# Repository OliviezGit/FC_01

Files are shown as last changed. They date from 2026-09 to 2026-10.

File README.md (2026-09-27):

# FC_01

Projet KiCad H743_Ardupilot.

Le [dossier composants](composants/README.md) contient les fiches techniques PDF, bibliothèques locales, STEP, vues de contrôle et la nomenclature France du 27/09/2026.

- [Contrôle PDF complet](composants/controle/CONTROLE_COMPLET.pdf)
- [BOM France et références à commander](composants/BOM_FR.csv)
- [Rapport de vérification et réserves](verification/REPORT.md)

La présence des fichiers est vérifiée. La fabrication reste non libérée et quatre références fabricant restent sans offre France confirmée.

## État PCB

- PCB : **6 couches cuivre** configurées.
- Huaqiu 90 Ω : **0,2037 mm / 0,2451 mm** enregistré dans le projet.
- Routage : **0 piste, 0 via, 0 zone**.
- Revue CEM/implantation : voir [verification/REPORT.md](verification/REPORT.md).

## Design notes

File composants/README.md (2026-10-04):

# Dossier composants FC_01

## Ajout de bibliothèque du 04/10/2026

Le symbole exact `H743_Ardupilot:LMR604305SRAKRQ1`, son empreinte dédiée `H743_Custom:TI_RAK0009A_WQFN-HR-9_2.5x2.0mm_LMR604305` et le STEP RAK0009A fourni sont disponibles dans les bibliothèques actives. [Comparaison du ZIP, corrections et contrôles](kicad/LMR604305SRAKRQ1_IMPORT.md). Cet ajout ne remplace aucun composant placé et ne modifie pas la nomenclature du circuit existant.

Contrôle du 27 septembre 2026. **Le dossier est complet pour la présence des fichiers, mais la fabrication et l'approvisionnement ne sont pas entièrement validés.**

- [Rapport PDF complet](controle/CONTROLE_COMPLET.pdf) : 114 pages, empreintes, vues 3D, variantes de symboles et éléments PCB.
- [Nomenclature France](BOM_FR.csv) : 44 références fabricant, 133 composants achetés, prix EUR HT, minimum tarifaire, stock relevé, référence à commander et liens.
- [Inventaire machine](catalogue.json) : associations exactes repères / symbole / empreinte / STEP / PDF / fournisseur.
- [PDF techniques](pdf/) : 35 documents fabricant, dont certains couvrent plusieurs références. [Sources et SHA-256](pdf/SOURCES.json).
- [Bibliothèques KiCad actives](kicad/) : utilisées par les tables du projet. Les anciens fichiers `extralib/` restent des instantanés historiques.
- [Modèles 3D](3d/) : fichiers STEP locaux et [associations/transformations](3d/BINDINGS.json).
- [Éléments PCB](ELEMENTS_PCB.csv) : 22 repères constitués de cuivre ou de trous; symbole et empreinte présents, aucun achat ni composant 3D séparé applicable.

## Résultat

Les 155 repères possèdent un symbole et une empreinte locaux. Les 133 composants achetés possèdent un fichier STEP associé dans la bibliothèque et dans le PCB. Le contrôle indépendant vérifie 560 correspondances broche/pastille, sans écart dans le périmètre analysé. La fusion avec main au commit 8d4ebe12 préserve les positions, orientations et faces courantes. C13, supprimé du schéma dans main, a été retiré du PCB et des nomenclatures. Les pads C35.1, R19.1 et R18.2 suivent désormais la correction ADC_VBAT2 du schéma.

## Propriétés dans les schémas KiCad

Les champs sont renseignés sur **chaque instance de composant** dans les fichiers `.kicad_sch`, et contrôlés contre le catalogue. Les anciens champs DigiKey avec espaces sont synchronisés; les anciens tarifs et références d'autres offres non vérifiées sont effacés pour éviter les contradictions.

| Champ de la propriété du symbole | Contenu |
|---|---|
| `Footprint` / `Footprint_File` | Identifiant KiCad et fichier d'empreinte local. |
| `Symbol_ID` / `Symbol_Library_File` | Variante de symbole utilisée et bibliothèque locale. |
| `Model_3D` / `Model_3D_Type` | Fichier STEP local et nature du modèle, y compris les enveloppes simplifiées. L'association 3D active se trouve dans l'empreinte et dans le PCB. |
| `Datasheet` / `Datasheet_URL` | PDF technique local et URL de sa source. |
| `Component_PDF` | PDF de contrôle avec symbole, empreinte et vue du modèle 3D. |
| `Supplier` / `Supplier_Order_Code` / `Supplier_URL` | Fournisseur France retenu, référence exacte à commander et lien. |
| `Unit_Price_EUR` / `Price_Basis` / `Price_Qty` | Prix par pièce en EUR HT et quantité minimale correspondant au tarif. |
| `Stock_Units` / `Supplier_Status` | Stock relevé et statut, avec distinction entre rupture et offre non confirmée. |
| `Price_Checked` / `Stock_Checked` / `Supplier_Notes` | Date de consultation et réserves sur le relevé. |

Les champs non confirmés restent vides et sont accompagnés du statut explicite. Les 22 éléments fabriqués dans le PCB (pastilles, trous, cavaliers cuivre) portent une mention « non applicable » pour l'achat et le modèle 3D séparé, et un lien vers leur PDF de contrôle. Les 127 symboles d'alimentation/réseau sont aussi vérifiés contre la bibliothèque locale; ils n'ont pas de composant physique à commander. Au total : **282 instances de symboles examinées**, dont 155 repères PCB.

Exports de contrôle : [champs par composant](../verification/SCHEMA_FIELDS.csv) et [toutes les instances de symboles](../verification/SCHEMA_SYMBOLS.csv).

Neuf MPN utilisent une **enveloppe reconstruite**, clairement indiquée dans chaque fiche : LMR43620R5RPER, LMR604303SRAKRQ1, TJA1051TK/3,118, BMP581, DPS368XTSA1, Everlight 19-337/R6GHBHC-M01/2T, CSTNE8M00GH5C000R0, XGL4030-332MEC et DX07S016JA1R1500. Une enveloppe représente l'encombrement renseigné, pas les contacts ni une validation des tolérances. Les autres modèles sont génériques KiCad ou issus du STEP Amphenol fourni. Les modèles LSM6DSV16X et ICM-45686 ont une hauteur adaptée respectivement à 0.83 et 0.81 mm.

Les archives SnapMagic USBLC6 et JAE fournies ont servi de comparaison. Leur licence interdit la redistribution isolée : leurs STEP originaux et leurs versions transformées ne sont pas ajoutés ici. U1 utilise le SOT-666 KiCad; USB1 utilise une enveloppe indépendante. Les symboles et empreintes spécifiques au projet restent intégrés au circuit; ce dossier n'est pas une bibliothèque fournisseur destinée à une redistribution séparée.

## Achats à résoudre

| Repères | MPN exact | Résultat |
|---|---|---|
| R1, R2 | 0402WGF5101TCE | Offre exacte non retrouvée chez Farnell, RS et DigiKey France; prix, stock et code de commande non confirmés. |
| D1 | 19-337/R6GHBHC-M01/2T | Même réserve. |
| R9 | RC0402FR-0716K5L | Référence trouvée à l'international, offre France non confirmée. |
| L1, L2 | XGL4030-332MEC | Fiche DigiKey Marketplace à l'international; disponibilité et tarif France non confirmés. |

Aucune substitution n'a été appliquée. Les données absentes sont laissées vides, jamais remplacées par zéro. Un stock nul indique une rupture sur la page consultée; un stock vide signifie non confirmé. Les disponibilités sont des relevés web, pas des réservations. Les pages peuvent être indexées avec retard.

Pour C1005X5R1C225M050BC, Farnell France 2525017 affiche 0.104 EUR HT par pièce **à partir de 10**, minimum et multiple de 10. La page indexée est ancienne et annonce une vente jusqu'à épuisement : prix et stock à reconfirmer. Le TJA1051TK/3,118 annonce une dernière date d'achat au 26/12/2026 sur DigiKey : cycle de vie à revoir avant approvisionnement.

## Contrôles restant ouverts

Voir [verification/REPORT.md](../verification/REPORT.md). ERC/DRC natifs KiCad non exécutés; le contrôleur indépendant ne développe pas les quatre nets du bus MOTOR. Les pads alternatifs U1/U10/U11, le masque U13, la pâte U5/U6 et le plan complet USB1 requièrent encore validation. Les quatre composants ajoutés dans la revue précédente restent en zone provisoire et leur placement/routage n'est pas terminé.

```sh
python3 tools/verify_design.py
python3 tools/check_connectivity.py
```

Les PDF de contrôle sont des rendus indépendants des fichiers KiCad, pas une sortie native de KiCad. Les numéros et connexions complets se trouvent dans [PINS.csv](../verification/PINS.csv). Les fiches techniques restent la référence pour les spécifications électriques complètes.

## Provenance

Les PDF fabricant et modèles tiers conservent leurs droits d'origine. Les commentaires de licence et noms d’auteur des STEP KiCad sont conservés. Une adresse personnelle présente dans un en-tête a été retirée; la section géométrique STEP est inchangée, et cette modification est tracée dans 3d/SOURCES.json. Les enveloppes paramétriques sont générées par `tools/localize_component_assets.py`; `tools/build_component_catalog.py` et `tools/render_component_catalog.py` régénèrent le catalogue. Dépendances : Python, CadQuery, NumPy, Matplotlib, PyMuPDF, ReportLab et polices DejaVu.

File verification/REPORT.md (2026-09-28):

# FC_01 — revue composants et bibliothèques

**Mise à jour du 28/09/2026 :** voir [RULES_LEVIA_COMPARISON_2026-09-28.md](RULES_LEVIA_COMPARISON_2026-09-28.md) pour les règles courantes, [PLACEMENT_NATIVE_DRC_2026-09-28.md](PLACEMENT_NATIVE_DRC_2026-09-28.md) pour le placement et [FULL_DESIGN_REVIEW_2026-09-28.md](FULL_DESIGN_REVIEW_2026-09-28.md) pour la revue fonctionnelle précédente. Les autres rapports et sections ci-dessous décrivent des révisions antérieures; leurs coordonnées et résultats ne doivent pas être utilisés pour le PCB courant.

Date : 2026-09-27. Base initiale : `8023e116a3f5c59ac772a055e0b58ddf85dce90a`. Fusion avec main : `8d4ebe12d84cf1e334181edc0c4434b1bac12989`.

**État : corrections intégrées, revue statique terminée ; fabrication non libérée.**
Le projet contient 155 références physiques, 44 MPN distincts et 560 broches/pads numérotés. Les 155 références disposent désormais d'un symbole et d'une empreinte résolus dans le dépôt. Le contrôle statique ne remplace pas KiCad ERC/DRC, une vérification électrique du circuit, ni une qualification d'assemblage.

## Revue implantation / CEM — mise à jour du 27/09/2026

Le PCB courant est désormais configuré en **6 couches cuivre** : F.Cu, In1.Cu, In2.Cu, In3.Cu, In4.Cu et B.Cu. Le routage n'a pas commencé : **0 segment, 0 via et 0 zone cuivre**. Le preset différentiel Huaqiu 90 ohms est enregistré dans le projet à **0,2037 mm de largeur / 0,2451 mm d'espacement**.

Les remarques CEM/implantation ont été rapprochées du fichier PCB courant :
- **USB1/U1/R1/R2** : le chevauchement courtyard a été supprimé. La marge courtyard USB1→U1 est d'environ **0,22 mm** ; la validation mécanique finale reste ouverte tant que le plan primaire coté JAE n'est pas archivé.
- **J12 microSD** : l'empreinte Amphenol 10067099-200LF Rev.H est intégrée ; la validation mécanique finale reste requise.
- **VCAP C7/C10** : corrigés sur **F.Cu**, au même côté que le STM32H743. C7 est maintenant à **(87,50 ; 94,05), 90°** et C10 à **(102,50 ; 98,40), 0°**, afin de réduire les boucles VCAP.
- **Y1 8 MHz** : reste actuellement sur **B.Cu**. Il ne doit pas être déplacé sur F.Cu sans réorganisation du bloc 9 V, car **L2 occupe actuellement la zone immédiatement sous OSC_IN/OSC_OUT**. Ce point reste bloquant avant routage.
- **U4/L2 9 V** : la cellule doit encore être repackée ; le feedback R10/R11 et la position de L2 sont à optimiser en même temps que le déplacement de Y1, avec nœud SW minimal et feedback éloigné de SW.
- **D5 / U8 CAN** : D5 est déjà placée au bord du connecteur U8 ; les courtyards sont séparés d'environ **0,47 mm**. Le routage devra conserver connecteur → protection ESD → transceiver sans stub.
- **BMI088 / BMP581** : les keepouts de routage/vias/métal constructeur restent à matérialiser dans KiCad avant routage.
- **Plans internes** : les 6 couches sont créées, mais les plans GND/POWER ne sont pas encore matérialisés par des zones ; la CEM finale ne pourra être validée qu'après routage, stitching et DRC.

## Modifications

| Référence | Correction appliquée |
|---|---|
| U14 | Empreinte JST SH 9 contacts remplacée par la variante SM08B à 8 contacts correspondant au MPN ; pattes 9/10 reliées GND. |
| U5, U6 | Empreinte dédiée Diodes U-DFN3030-8 Type E ; EP 1.60 × 2.35 mm et pads périphériques conformes au plan. Fenêtres de pâte EP à qualifier avec l'assembleur. |
| D2 | Empreinte Diodes SMA avec pads 2.50 × 1.70 mm, centres espacés de 4.00 mm. Ancien modèle Littelfuse conservé dans ses fichiers historiques, mais plus affecté à D2. |
| U12 | Dimensions des six pads haut/bas BMP581 corrigées à 0.300 × 0.325 mm ; ouverture masque sous corps ajoutée selon Bosch. |
| D1 | Noms de broches corrigés : 1 BK, 2 RK, 3 GK, 4 BA, 5 RA, 6 GA ; numéros et fils conservés. Empreinte Everlight dédiée ajoutée. |
| U11 | Empreinte LGA14 ajoutée ; cinq marqueurs NC déplacés sur les extrémités des broches. **GND reste en 6 et VDD en 8**, comme indiqué par TDK. |
| U13, Y1 | Empreintes locales DPS368 et résonateur Murata ajoutées. |
| R34, R35, R36 | Affectations des nets aux pads 1/2 du PCB remises en accord avec le schéma. |
| D4, D5, U8 | Liens datasheet, noms de pins D5 et métadonnée de boîtier GH corrigés. |

Y1, D1, U11 et U13 sont désormais intégrés au PCB courant ; l'ancienne zone d'attente à x=230 mm n'est plus l'état de référence. Le placement actuel du PCB fait foi. Y1 reste néanmoins à reprendre côté F.Cu après réorganisation du bloc 9 V, comme indiqué dans la revue implantation/CEM ci-dessus. C13, supprimé du schéma dans main, est retiré du PCB et des nomenclatures (151 empreintes héritées conservées). La correction ADC_VBAT2 du schéma est reportée sur C35.1, R19.1 et R18.2; aucun segment routé ne portait cet ancien net. Les nets internes hérités de noms de pins D1 peuvent conserver leur ancien libellé ; les connexions numériques sont inchangées.

Les symboles utilisés sont figés dans `composants/kicad/FC01_Project.kicad_sym`, avec un nom distinct par feuille/variante pour préserver les personnalisations. Les empreintes standard utilisées sont copiées depuis le PCB dans `composants/kicad/vendor/` et référencées par `fp-lib-table`. Il s'agit d'instantanés de ce projet, pas d'une mise à jour vers la dernière bibliothèque KiCad. Les 133 composants achetés disposent de modèles STEP locaux. Neuf MPN utilisent une enveloppe reconstruite, sans contacts détaillés; voir `../composants/3d/BINDINGS.json`. Les fichiers `extralib/` historiques restent conservés, mais les tables pointent désormais sur `composants/kicad/`.

La nomenclature actuelle est `../composants/BOM_FR.csv`. Prix et stocks ont été recherchés sur les sites France le 27/09/2026. Quatre MPN restent sans offre France confirmée. Le tarif Farnell C1005X5R1C225M050BC est à partir de 10 pièces et sa source indexée est ancienne. `BOM_DigiKey.csv` est synchronisé avec ces données.

## Preuves et portée

- [COMPONENTS.csv](COMPONENTS.csv) : une ligne par référence, MPN, boîtier, symbole, empreinte, statut et source.
- [PINS.csv](PINS.csv) : une ligne par pin avec nom, net PCB, NC et dimensions/positions de pad. Pour les pads `custom`, `size` est la taille de l'ancre ; le polygone complet fait foi.
- [EVIDENCE.json](EVIDENCE.json) : constat par MPN, détails dimensionnels et réserves.
- [SOURCE_HASHES.json](SOURCE_HASHES.json) : empreintes SHA-256 des PDF effectivement téléchargés et examinés. Les 35 PDF techniques sont désormais archivés dans `../composants/pdf/`; le manifeste courant est `../composants/pdf/SOURCES.json`.
- [CHECKS.json](CHECKS.json) : résultats du contrôle reproductible.
- [SCHEMA_FIELDS.csv](SCHEMA_FIELDS.csv) : propriétés effectivement enregistrées sur les 155 instances de composants des schémas, avec liens locaux, données d'achat et réserves.
- [SCHEMA_SYMBOLS.csv](SCHEMA_SYMBOLS.csv) : les 282 instances de symboles, y compris les 127 symboles d'alimentation/réseau sans composant physique.

Les statuts `MANUFACTURER_LAND_*` concernent les dimensions citées, pas une certification de fabricabilité. `PACKAGE_REVIEWED_STANDARD_LAND` et `FAMILY_PACKAGE_REVIEWED` indiquent un boîtier/famille reconnu avec empreinte standard conservée ; ils ne prétendent pas reproduire un land pattern constructeur spécifique. Les listes de pins exportées constituent une preuve de cohérence des fichiers, pas à elles seules une validation indépendante de toutes les fonctions électriques.

## Contrôles exécutés

Depuis la racine du dépôt :

```sh
python3 tools/verify_design.py
python3 tools/check_connectivity.py
```

Le validateur vérifie : ensembles de références, résolution des bibliothèques locales, égalité symbole embarqué/bibliothèque, ensembles de numéros de pins/pads, géométrie des pads PCB/bibliothèque après normalisation de face/orientation, rattachement UUID et cohérence des groupes de nets. Il ne modifie aucun fichier sans `--write`.

Il contrôle également les propriétés de chaque composant du schéma contre le catalogue, l'existence de ses fichiers locaux et la cohérence des anciens champs commerciaux avec le fournisseur France retenu. Les prix non confirmés sont vides. Les anciens champs USB1 (tarif de bobine et URL erronée), C7/C10 (ancienne offre DigiKey) et les autres valeurs périmées ont été corrigés; les 3D simplifiées restent explicitement identifiées.

Résultat : **155/155 références, 560 pins/pads, zéro erreur dans le périmètre analysé**. La géométrie des nouveaux pads a également été examinée sur un rendu technique indépendant. Les quatre nets `/MCU/MOTOR1` à `/MCU/MOTOR4` traversent un bus vectoriel que le script ne développe pas : ils sont explicitement exclus du rapprochement entre groupes et restent à vérifier nativement. Les alias de bus et les croisements complexes requièrent aussi le contrôle natif.

## Points ouverts avant fabrication

1. **KiCad 10** : ouvrir le projet, mettre à jour le PCB depuis le schéma (F8), comparer les changements proposés, exécuter ERC puis DRC après placement/routage. `kicad-cli` n'est pas disponible ici ; aucun résultat ERC/DRC natif n'est annoncé.
2. **USB1/JAE** : obtenir le plan coté complet et valider les ancrages/courtyard avant fabrication. Le STEP fourni a été orienté et ses contacts rapprochés des pads. **J12/Amphenol** : plan Rev.H maintenant archivé et relu, STEP orienté, corps et contacts cohérents avec le plan; validation d’assemblage reste requise.
3. **L1/L2 Coilcraft** : le plan mécanique document 1575-4 du 19/12/2022 est maintenant archivé et confirme les pads 0.98 × 3.40 mm, entraxe 2.37 mm. L’offre commerciale France reste non confirmée. Le modèle local est une enveloppe nominale.
4. **U1/U10/U11** : confirmer avec l'assembleur les pads alternatifs conservés/créés. Pour U1, l'empreinte fournisseur SOT-666 est conservée ; elle diffère du dessin conseillé par ST. Pour U11, les dimensions du boîtier et le brochage sont confirmés, mais les extensions de pads sont un choix IPC de projet.
5. **U13 et U5/U6** : approuver respectivement le recouvrement masque SMD choisi (cuivre 0.45, ouverture 0.35 mm) et les quatre fenêtres de pâte thermique. Contrôler les contraintes de montage/nettoyage des capteurs de pression.
6. Réaliser le placement, les dégagements mécaniques, le routage, les contrôles d'alimentation/intégrité des signaux et les sorties de fabrication. Cette revue ne certifie pas le fonctionnement du contrôleur de vol.

Les anciens rapports d'audit du dépôt décrivent des états antérieurs. Pour les modifications de cette révision, ce dossier et les fichiers de conception courants font foi.

## Complément documentaire et approvisionnement

Voir [composants/README.md](../composants/README.md) et le [contrôle PDF complet](../composants/controle/CONTROLE_COMPLET.pdf). Les tests vérifient désormais aussi présence locale et égalité des associations 3D PCB/bibliothèque. Les modèles d’enveloppe ne sont pas des modèles détaillés certifiés fabricant.

## Corrections CEM / pré-routage — 27/09/2026 soir

- Netclasses KiCad créées : `POWER`, `USB_90R`, `CAN`, `SENSITIVE`; affectations initiales enregistrées dans le projet. La géométrie USB reste à recalculer/valider contre le stack-up fabricant réel avant routage.
- Cellule 9 V : R10/R11 rapprochées de U4/FB, L2 éloignée de la zone oscillateur; C19 rapprochée de U4. Le routage SW/PGND/FB reste à réaliser selon la boucle minimale du constructeur.
- Buck 5 V : C17 rapprochée de U3 VIN/GND.
- U7 : TJA1051TK/3,118 EOL remplacé au schéma par TJA1057GTK/3Z, brochage /3 et boîtier HVSON8/SOT782 compatibles à conserver lors de la synchronisation PCB.
- D2 : SMAJ30CA non validée pour protection des buck 42 V (clamp max trop élevé). SMAJ24CA identifiée comme piste de correction, mais non imposée car VRWM=24 V est inférieur au 25,2 V d'un pack 6S plein; choix final de protection transitoire encore ouvert.
- Y1 : déplacement final et zone oscillateur dédiée encore ouverts; aucune implantation arbitraire n'a été imposée.
- BMI088/BMP581 : keepouts constructeur cuivre/vias encore à matérialiser précisément dans le PCB.
- SDIO_CLK : résistance série optionnelle encore à intégrer proprement au schéma + PCB; ne pas modifier seulement le PCB.

## Pré-routage CEM — application 27/09/2026

- Y1: zone oscillateur matérialisée; résonateur rapproché du MCU, keepout cuivre/vias local B.Cu et keepout opposé F.Cu pour interdire un convertisseur directement en vis-à-vis.
- BMI088 U9: keepout footprint corrigé pour être local au composant et couvrir la zone sous boîtier; pistes/vias/copper pour interdits dans la zone définie.
- BMP581 U12: keepout sous boîtier ajouté, avec pistes/vias/copper pour interdits; pads autorisés.
- SDIO_CLK: R47 22 ohms ajoutée en série côté source dans MICRO_SD, 0402; option 0 ohm après validation SI. Empreinte synchronisée sur PCB et net carte séparé.
- D2 / architecture VBAT: décision gelée — conserver SMAJ30CA, U3 LMR43620 et U4 LMR60430-Q1. Pas d'eFuse/clamp actif et pas de passage à des buck 60–100 V. Le système est conçu pour VBAT 6S (25,2 V max normal); la SMAJ30CA est une protection transitoire, pas une garantie de clamp <42 V dans toutes les conditions.
- Plans GND In1/In4 ajoutés, ainsi qu'une première couronne de vias de stitching GND périphériques.
- Routage signal complet NON réalisé: le PCB était encore à 0 segment avant cette passe et un routage automatique non revu serait contraire à l'objectif CEM. Les boucles buck, USB 90 ohms, CAN et retours capteurs doivent être routés/revus explicitement.
- ERC/DRC KiCad 10 NON exécuté dans cet environnement: kicad-cli n'est pas disponible. Ne pas considérer la carte libérable avant ouverture/sauvegarde KiCad 10 puis ERC/DRC natifs.

## Décision architecture VBAT / D2 / buck — 27/09/2026

Décision finale pour cette révision: conserver l'architecture simple existante.

- Entrée: VBAT 6S, 25,2 V maximum en fonctionnement normal.
- D2: SMAJ30CA conservée.
- U3: LMR43620 conservé.
- U4: LMR60430-Q1 conservé.
- Aucun eFuse/clamp actif ajouté.
- Aucun remplacement des buck par des versions 60/80/100 V.
- D2 doit rester implantée au plus près de l'entrée VBAT/GND avec boucle de décharge courte et large.
- Les condensateurs d'entrée de chaque buck doivent rester directement associés aux broches VIN/PGND; minimiser les boucles chaudes VIN-SW-PGND.
- Limite documentée: la valeur Vc maximale de la SMAJ30CA à son courant d'essai peut dépasser 42 V; D2 réduit les surtensions mais n'est pas spécifiée comme écrêteur garanti sous l'absolute maximum des buck pour toute impulsion possible.
- Cette limitation est acceptée pour la révision 6S actuelle; elle devra être réévaluée si l'entrée batterie, le câblage, l'ESC, la capacité bulk ou la tension maximale changent.

## Revue placement / corrections — 27/09/2026

- Collision de référence corrigée: la résistance série SDIO_CLK est désormais R51 (22 ohms, option 0 ohm après validation SI). R47 reste exclusivement la résistance MOTOR1 200 ohms.
- PCB synchronisé manuellement pour R51; net SDIO_CLK -> R51 -> J12 CLK conservé.
- L2 déplacée légèrement à (91.6,117.6) pour augmenter l'écart à Y1 sans allonger excessivement la boucle SW U4-L2. Le routage SW_9V devra rester compact et orienté à l'opposé de Y1.
- Découplages H743 rapprochés de la périphérie MCU: C6, C8, C11, C12. Les couloirs d'évasion du LQFP100 sont conservés; aucune piste n'est encore routée.
- Découplages capteurs resserrés: C44/C47 autour de U11, C46/C49/C52 autour de U9, C53 autour de BMP581. U10 était déjà correctement découplé localement.
- Connectique contrôlée: CAN J13/J14/U8 reste sur la périphérie; I2C J8/J9 en bord inférieur; ESC U14 en bord gauche; USB1 en bord supérieur. Cette organisation est conservée pour éviter des traversées inutiles de la zone MEMS.
- Séparation puissance/capteurs: L1/U3 restent côté gauche; U9/U10/U11/U12/U13 côté droit. Les nets SW_5V et SW_9V ne devront pas être routés sous la zone MEMS ni sous Y1.
- Statut: placement nettement plus proche du gel, mais validation DRC et inspection visuelle KiCad 10 requises avant freeze définitif.

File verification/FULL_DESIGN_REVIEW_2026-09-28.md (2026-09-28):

# FC_01 — revue schéma, PCB, empreintes et placement (28/09/2026)

État du PCB : **pré-routage, non libéré pour fabrication**. Les deux faces F.Cu/B.Cu et les trous traversants ont été examinés. Les 22 références figées (connecteurs, fixations, U8, U14, USB1) restent à leur emplacement initial.

## Corrections de cette passe

| Cellule | Changement | Résultat géométrique |
|---|---|---|
| U6, C30, C32 | U6 orienté 270°; condensateurs entrée/sortie remis du côté de leurs broches respectives | U6.8→C30.1 : **5,02 → 2,14 mm**; U6.1→C32.1 : **1,61 → 1,93 mm**. Trous USB1 libres. |
| U5, C29, C31 | U5 et ses deux condensateurs retournés sur place, pads alimentation vers le LDO | U5.8→C29.1 : **3,51 → 1,96 mm**; U5.1→C31.1 : **3,66 → 2,23 mm**. |
| U3, L1 | L1 retournée sans déplacer son corps | Broche SW U3.5→L1.1 : **3,87 → environ 3,43 mm**. |
| U9 BMI088 | Ouverture de pâte des 16 pads périphériques diminuée de 0,025 mm par côté sur le PCB et l'empreinte locale | Ouverture 0,20 × 0,625 mm pour pad 0,25 × 0,675 mm : **74,1 % de l'aire cuivre**. |

Les distances sont entre centres de pads, en projection 2D : elles aident à comparer les implantations mais ne mesurent ni longueur routée ni aire de boucle. Aucun composant figé n'a bougé.

## Rapprochement statique

| Contrôle | Résultat |
|---|---|
| Schéma ↔ PCB | **156/156 références**, **562/562 couples broche/pad**; empreintes PCB ↔ bibliothèques locales cohérentes; zéro erreur dans `verify_design.py`. |
| Réseaux | 456 broches avec noms de nets comparées indépendamment; zéro discordance. Aucune fusion ou séparation inattendue des groupes. Les quatre couples MCU↔résistance MOTOR1–4 sont comparés explicitement; développement complet des bus à contrôler dans KiCad. |
| Courtyards F.Cu/B.Cu | Aucun recouvrement entre composants d'une même face détecté par `audit_placement.py`. |
| Face opposée / traversants | Aucun contact trou traversant ↔ pad SMD ou courtyard opposé détecté par `audit_through_holes.py`; la projection seule des composants sur deux faces n'est pas une collision physique. |
| Oscillateur et références figées | Y1 du même côté F.Cu que U2; keepout opposé libre; 22 références figées sans déplacement. |
| Routage | **0 piste, 0 via, 2 zones**. Les deux zones ne remplacent pas un remplissage et un DRC natif. |

## Comparaison aux fiches constructeur archivées

| Bloc | Prescription vérifiée | Constat / point restant |
|---|---|---|
| U5/U6 AP7361C | Au moins 1 µF à l'entrée, 2,2 µF à la sortie, céramiques proches de IN/OUT et GND ([fiche](../composants/pdf/AP7361C.pdf)). | C29–C32 : 4,7 µF nominaux; les pads d'alimentation sont à 1,93–2,23 mm des broches utiles. Capacité effective sous polarisation et retour GND à confirmer. |
| U3 LMR43620 | CIN, VCC, BOOT proches; nœud SW court; FB à l'écart du SW ([fiche](../composants/pdf/U3_datasheet.pdf), §9.5.1). | U3→C16 1,88 mm; →C20 1,60 mm; →C21 2,74 mm; SW→L1 ~3,43 mm. Boucles et masse à mesurer après routage. |
| U4 LMR60430-Q1 | Même discipline CIN/BOOT/SW/FB et cuivre thermique ([fiche](../composants/pdf/U4_datasheet.pdf), §8.4.1). | U4→C19 1,61 mm; →C22 2,55 mm; FB→R10 1,22 mm; SW→L2 4,03 mm. Chemin SW, dissipation, épaisseur de cuivre et masse restent à valider. |
| U2 STM32H743, Y1 | Découplage et VCAP près des broches; résonateur HSE proche des entrées ([fiche](../composants/pdf/U2_datasheet.pdf)). | U2→C7 1,88 mm, →C10 1,94 mm; Y1 sur F.Cu, à 4,13/3,19 mm des broches HSE. VCAP 2,2 µF nominal; ESR et capacité effective à confirmer. |
| U9 BMI088 | Stencil signal 70–90 % de la surface pad, épaisseur 80–150 µm ([fiche](../composants/pdf/U9_datasheet.pdf), §8.5). | 74,1 % après correction; épaisseur de stencil à spécifier à l'assembleur. U9 est sous la projection du MCU sur l'autre face : vérifier mécanique/thermique. |
| U12 BMP581 | Pad allongé de 25 µm, séparation ≥200 µm, ni piste ni via sous le capteur; contraintes de masque ([fiche](../composants/pdf/U12_datasheet.pdf), §8.2). | Keepout local B.Cu et pads 0,300 × 0,325 mm présents. Les couches internes et la fenêtre de masque sous le corps restent à confirmer dans KiCad et auprès de l'assembleur. |
| USB1 | Validation du connecteur JAE et des ancrages. | Trous et pads dégagés sur les deux faces. Le PDF JAE archivé n'est pas un plan coté complet : validation mécanique fabricant encore ouverte. |

## Avant libération

Ouvrir le projet dans KiCad, mettre à jour le PCB depuis le schéma en examinant le diff, exécuter ERC puis DRC natifs, remplir les zones et router. Contrôler alors impédance USB selon l'empilage réel, retours de courant, boucles SW, chemins de protection ESD et dégagements 3D. Examiner les points ouverts U12, USB1, VCAP et stencil avec les fiches et l'assembleur. **Aucun ERC/DRC natif n'a été exécuté dans cet environnement**, où `kicad-cli`/`pcbnew` ne sont pas installés; ce rapport ne certifie pas le fonctionnement électrique ou la fabricabilité.

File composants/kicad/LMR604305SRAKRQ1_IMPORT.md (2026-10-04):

# LMR604305SRAKRQ1 — bibliothèque FC_01

Mise à jour du 04/10/2026 à partir de l'archive `LMR604305SRAKRQ1.zip` fournie par l'utilisateur et de la fiche TI LMR60430-Q1, SNAS875E, révision E.

## Utilisation dans KiCad

- Symbole : `H743_Ardupilot:LMR604305SRAKRQ1`.
- Empreinte : `H743_Custom:TI_RAK0009A_WQFN-HR-9_2.5x2.0mm_LMR604305`.
- STEP : `${KIPRJMOD}/composants/3d/LMR604305SRAKRQ1_RAK0009A.step`.
- Les tables de bibliothèques du projet enregistrent déjà `H743_Ardupilot` et `H743_Custom`; aucune configuration supplémentaire n'est nécessaire.

Le composant est disponible pour insertion. Cette mise à jour des bibliothèques ne remplace aucun composant dans les schémas ou dans le PCB.

## Comparaison et corrections

Le symbole du ZIP comporte le brochage exact de la référence 5 V. Ses types électriques SW `power_in` et FB/MODE/RT `unspecified` ne sont pas repris tels quels. Le symbole ajouté utilise la présentation compacte existante du projet, les types ci-dessous et la référence fabricant exacte. Aucun code fournisseur de la référence 3,3 V n'est recopié.

| Broche | Fonction | Type KiCad |
|---|---|---|
| 1 | VIN | power_in |
| 2 | PGND | power_in |
| 3 | SW | power_out |
| 4 | BOOT | passive |
| 5 | PG | open_collector |
| 6 | FB | input |
| 7 | MODE/SYNC | input |
| 8 | RT | passive |
| 9 | EN | input |

BOOT est passif pour représenter le raccordement bootstrap par condensateur sans demander une source d'alimentation externe sur ce nœud. RT est passif pour représenter sa résistance de programmation; PG est une sortie à drain ouvert représentée par le type KiCad `open_collector`.

L'empreinte brute du ZIP dessine plusieurs plages de cuivre comme graphiques `F.Cu`, séparées des pastilles circulaires, et numérote les trois trous thermiques 10, 11 et 12. Ces numéros ne sont pas des broches du composant RAK à neuf broches. L'empreinte intégrée reprend les pastilles personnalisées électriquement connectées de FC_01, ses ouvertures de masque et de pâte, son repère de broche 1 et sa cour intérieure, avec le STEP fourni. Elle ne contient ni cuivre graphique flottant ni pastille 10–12. Les vias thermiques éventuels doivent être posés sur le réseau PGND pendant le routage; les recommandations TI de remplissage, bouchage ou tenting doivent être prises en compte selon le procédé de fabrication.

La géométrie cuivre/masque/pâte est conservée à l'identique de l'empreinte locale existante. Une variante dédiée à la référence 5 V évite de changer les associations historiques et les empreintes déjà placées.

## Contrôles exécutés

- Lecture structurée des fichiers KiCad et absence de noms de symboles dupliqués.
- Les sept symboles précédents de la bibliothèque sont conservés à l'identique; un huitième symbole est ajouté.
- Brochage 1–9 comparé au symbole fourni et à la table TI, page 4.
- Contrôle des neuf pastilles électriques, du lien symbole/empreinte et des chemins de bibliothèques actifs.
- Comparaison de la géométrie au fichier local précédent et revue du plan TI RAK0009A, pages 43–45.
- STEP fourni lu par OpenCascade : dix solides, neuf contacts alignés sur les neuf pastilles; encombrement 2,0 × 2,5 × 0,8 mm et origine de montage Z = 0.
- Le STEP est copié sans modification. SHA-256 : `45047d72ab90321aa5fd37295c414bddf8963955413e9c0bb3c3ade36f1926e9`.

KiCad natif n'est pas installé dans cet environnement : ces contrôles ne constituent pas un ERC/DRC natif ni une validation de fabrication. La validation électrique du convertisseur, son implantation, ses vias thermiques et son intégration au schéma restent distinctes de cette mise à jour de bibliothèque.

Source TI : https://www.ti.com/lit/gpn/LMR60430-Q1

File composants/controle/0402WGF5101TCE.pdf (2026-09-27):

FC_01 / DOSSIER COMPOSANTS / 27.09.2026

# 0402WGF5101TCE

R1 / R2

UNI-ROYAL(Uniroyal Elec) - 5.1K -

Quantité carte : 2 | Broches et pastilles : contrôle structurel concordant.
Achat : Farnell / RS / DigiKey France | référence commande non confirmée
Prix : NON CONFIRMÉ | Stock relevé : non confirmé

Reference exacte: offre France, prix et stock non confirmes. Ne pas commander via une substitution implicite.

PDF technique local : composants/pdf/Royalohm.pdf
Lien de téléchargement de la fiche technique (https://www.royalohm.com/assets/pdf/products/smd/1.pdf)
EMPREINTE / mm | MODÈLE 3D LOCAL

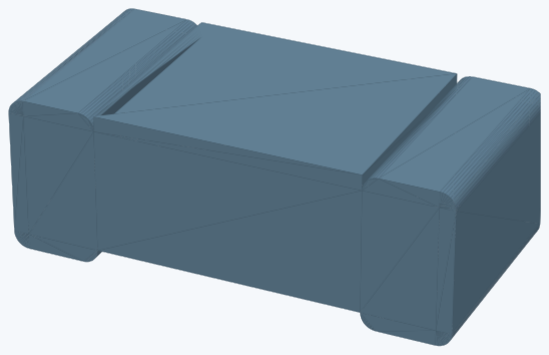
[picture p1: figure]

1 2

Cuivre ocre / corps bleu / cour dessin gris - vue dessus

3D : KiCad, geometrie generique du boitier

Empreinte : Resistor_SMD:R_0402_1005Metric
STEP : composants/3d/R_0402_1005Metric.step

Contrôle documentaire : Royalohm Thick Film Chip Resistors pp.1,3: 0402 1.00±0.10 x 0.50±0.05 mm; code 5101=5.1 kohm, F=1%. Deux bornes non polarisées; pads KiCad conservés.

Lecture indépendante des fichiers KiCad. Aucun ERC/DRC natif exécuté. | 1

FC_01 / DOSSIER COMPOSANTS / 27.09.2026

# 0402WGF5101TCE

SYMBOLE / FC01_Project:H743_Ardupilot__R_Small

Repères : R1, R2

SYMBOLE / CORPS ET NUMÉROS DES BROCHES

1

2

Correspondance complète : verification/PINS.csv

Rendu vectoriel de la variante utilisée; champs de nomenclature en page précédente. | 2

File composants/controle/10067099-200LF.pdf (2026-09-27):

FC_01 / DOSSIER COMPOSANTS / 27.09.2026
10067099-200LF

J12

Amphenol ICC (FCI) - 10067099-200LF - microSD, SMD right-angle top-mount, 10 positions (8+2), H=2.65 mm

Quantité carte : 1 | Broches et pastilles : contrôle structurel concordant.
Achat : DigiKey France | 609-5773-1-ND
Prix : 0.7800 EUR HT / pièce, tarif quantité 1 | Stock relevé : 32954

Ouvrir la fiche fournisseur France (https://www.digikey.fr/fr/products/detail/amphenol-icc-fci/10067099-200LF/4238739)

Relevé web; stock et prix variables.

PDF technique local : composants/pdf/10067099.pdf Lien de téléchargement de la fiche technique (https://www.mouser.com/datasheet/2/18/1/10067099-2577377.pdf)

EMPREINTE / mm | MODÈLE 3D LOCAL

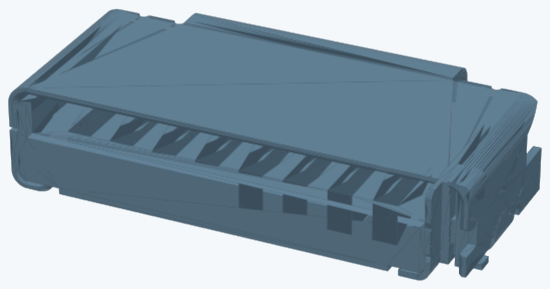
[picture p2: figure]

8 | 7 | 6 | 5 | 4 | 3 | 2 | 1

10

9

Cuivre ocre / corps bleu / cour dessin gris - vue dessus

3D : STEP fournisseur fourni par utilisateur; orientation rapprochee du plan Rev.H

Empreinte : H743_Custom:Amphenol_10067099-200LF_RevH
STEP : composants/3d/Amphenol_10067099-200LF_aligned.step

Contrôle documentaire : Plan Amphenol 10067099 Rev.H p.2: version 200LF hauteur 2.65 mm, 8 contacts pas 1.10 mm + 2 detecteurs. Plan local et STEP fournisseur rapproches de l empreinte; validation assemblage reste a faire.

Lecture indépendante des fichiers KiCad. Aucun ERC/DRC natif exécuté. | 1

FC_01 / DOSSIER COMPOSANTS / 27.09.2026
10067099-200LF

SYMBOLE / FC01_Project:MICRO_SD__Micro_SD_Card

Repères : J12

SYMBOLE / CORPS ET NUMÉROS DES BROCHES

1
DAT2

2
DAT3/CD

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
DAT0

8
DAT1

9

CD1

# 10CD²

Correspondance complète : verification/PINS.csv

Rendu vectoriel de la variante utilisée; champs de nomenclature en page précédente. | 2

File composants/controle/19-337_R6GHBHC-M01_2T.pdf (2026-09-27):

FC_01 / DOSSIER COMPOSANTS / 27.09.2026

# 19-337/R6GHBHC-M01/2T

D1

Everlight Electronics - 19-337/R6GHBHC-M01/2T - 6-SMD, 1.6x1.6x0.35 mm

Quantité carte : 1 | Broches et pastilles : contrôle structurel concordant.
Achat : Farnell / RS / DigiKey France | référence commande non confirmée
Prix : NON CONFIRMÉ | Stock relevé : non confirmé

Reference exacte: offre France, prix et stock non confirmes. Ne pas commander via une substitution implicite.

PDF technique local : composants/pdf/D1_datasheet.pdf
Lien de téléchargement de la fiche technique (https://uploadcdn.oneyac.com/attachments/files/brand_pdf/everlight/BB/85/19337R6GHBHCM012T.pdf)
EMPREINTE / mm | MODÈLE 3D LOCAL

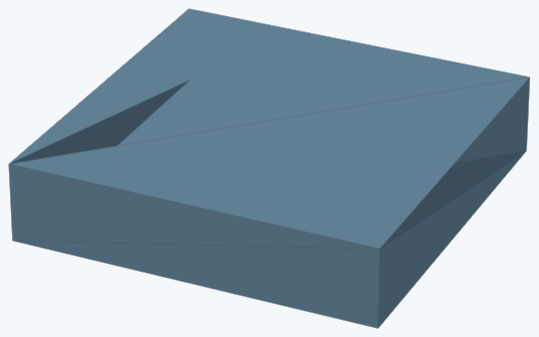
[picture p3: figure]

1

2

3

4

5

6

Cuivre ocre / corps bleu / cour dessin gris - vue dessus

3D : ENVELOPPE RECONSTRUITE: volume du boitier uniquement; contacts et tolerances non representes

Empreinte : H743_Custom:Everlight_19-337_1.6x1.6mm
STEP : composants/3d/Everlight_19-337_envelope.step

Contrôle documentaire : Everlight DSE0007440 Rev2 p.2: 1BK 2RK 3GK 4BA 5RA 6GA. Noms corrigés sans changer numéros/fils. Corps 1.6 x 1.6; centres x±0.7, y±0.75 et 0; pads extrêmes 0.6 x 0.5, centraux 0.6 x 0.6. Placement PCB à terminer.

Lecture indépendante des fichiers KiCad. Aucun ERC/DRC natif exécuté. | 1

FC_01 / DOSSIER COMPOSANTS / 27.09.2026

# 19-337/R6GHBHC-M01/2T

SYMBOLE / FC01_Project:MCU__LED_RGB_EP_1

Repères : D1

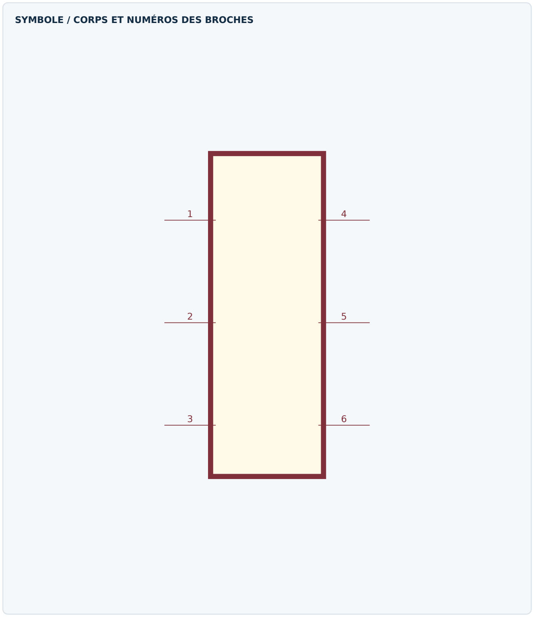
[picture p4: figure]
SYMBOLE / CORPS ET NUMÉROS DES BROCHES

Correspondance complète : verification/PINS.csv

Rendu vectoriel de la variante utilisée; champs de nomenclature en page précédente. | 2

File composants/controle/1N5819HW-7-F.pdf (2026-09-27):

FC_01 / DOSSIER COMPOSANTS / 27.09.2026

# 1N5819HW-7-F

D4

Diodes Incorporated - 1N5819HW-7-F - SOD-123

Quantité carte : 1 | Broches et pastilles : contrôle structurel concordant.
Achat : DigiKey France | 1N5819HW-FDICT-ND
Prix : 0.2700 EUR HT / pièce, tarif quantité 1 | Stock relevé : 711720

Ouvrir la fiche fournisseur France (https://www.digikey.fr/fr/products/detail/diodes-incorporated/1N5819HW-7-F/814970)

Relevé web; stock et prix variables.

PDF technique local : composants/pdf/1N5819HW.pdf Lien de téléchargement de la fiche technique (https://media.digikey.com/pdf/Data%20Sheets/Diodes%20PDFs/1n5819hw%20%202.pdf)

EMPREINTE / mm | MODÈLE 3D LOCAL

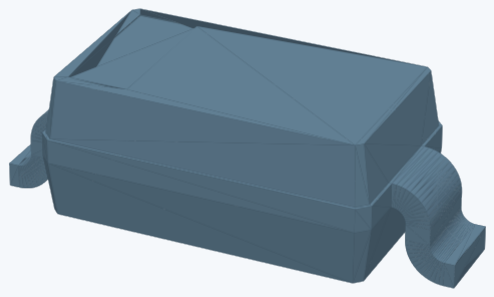
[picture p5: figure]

1 2

Cuivre ocre / corps bleu / cour dessin gris - vue dessus

3D : KiCad, geometrie generique du boitier

Empreinte : Diode_SMD:D_SOD-123
STEP : composants/3d/D_SOD-123.step

Contrôle documentaire : Diodes 1N5819HW-7-F: SOD-123, 1 cathode 2 anode. Lien datasheet corrigé (ancienne fiche Hottech 1N5819WS incorrecte).

Lecture indépendante des fichiers KiCad. Aucun ERC/DRC natif exécuté. | 1

FC_01 / DOSSIER COMPOSANTS / 27.09.2026

# 1N5819HW-7-F

SYMBOLE / FC01_Project:POWER__1N5819WS

Repères : D4

SYMBOLE / CORPS ET NUMÉROS DES BROCHES

1 | 2

Correspondance complète : verification/PINS.csv

Rendu vectoriel de la variante utilisée; champs de nomenclature en page précédente. | 2

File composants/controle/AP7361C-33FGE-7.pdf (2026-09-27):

FC_01 / DOSSIER COMPOSANTS / 27.09.2026

# AP7361C-33FGE-7

U5 / U6

Diodes Incorporated - AP7361C-33FGE-7 - U-DFN3030-8 Type E; exposed pad 1.6 x 2.35 mm

Quantité carte : 2 | Broches et pastilles : contrôle structurel concordant.
Achat : DigiKey France | AP7361C-33FGE-7DICT-ND
Prix : 0.4900 EUR HT / pièce, tarif quantité 1 | Stock relevé : 3118

Ouvrir la fiche fournisseur France (https://www.digikey.fr/en/products/detail/diodes-incorporated/AP7361C-33FGE-7/5638320)

Relevé web; stock et prix variables.

PDF technique local : composants/pdf/AP7361C.pdf Lien de téléchargement de la fiche technique (https://docs.sparkfun.com/SparkFun_GNSS_Flex_System/SparkFun_GNSS_Flex_Breakout/assets/component_documentation/AP7361C.pdf)

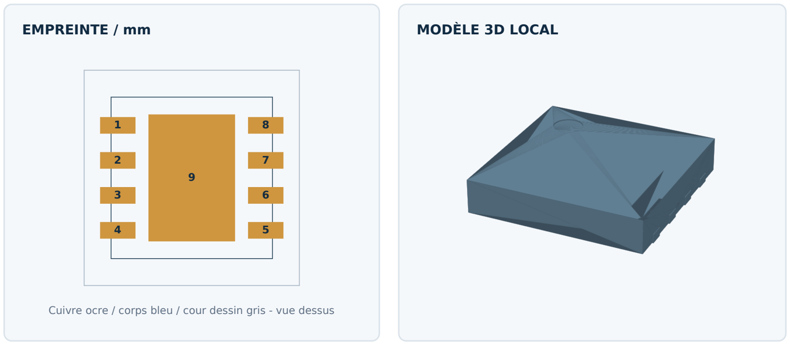
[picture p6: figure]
EMPREINTE / mm; MODÈLE 3D LOCAL

Cuivre ocre / corps bleu / cour dessin gris - vue dessus

3D : KiCad: EP nominal 1.5 x 2.25, pads PCB maximaux 1.6 x 2.35 (Diodes p.17/20)

Empreinte : H743_Custom:Diodes_U-DFN3030-8_TypeE
STEP : composants/3d/DFN-8-1EP_3x3mm_P0.65mm_EP1.5x2.25mm.step

Contrôle documentaire : AP7361C FGE = U-DFN3030-8 Type E. Pads périphériques 0.65 x 0.30, pas 0.65; EP9 1.60 x 2.35 mm. Stencil EP découpé en 4 fenêtres, couverture 64% (choix projet à qualifier). EP relié GND; pads NC conservés.

Lecture indépendante des fichiers KiCad. Aucun ERC/DRC natif exécuté. | 1

FC_01 / DOSSIER COMPOSANTS / 27.09.2026

# AP7361C-33FGE-7

SYMBOLE / FC01_Project:POWER__AP7361C-33FGE-7

Repères : U5, U6

SYMBOLE / CORPS ET NUMÉROS DES BROCHES

1
OUT

2
NC

3
ADJ/NC

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
Correspondance complète : verification/PINS.csv

Rendu vectoriel de la variante utilisée; champs de nomenclature en page précédente. | 2

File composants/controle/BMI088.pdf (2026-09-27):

FC_01 / DOSSIER COMPOSANTS / 27.09.2026

# BMI088

U9

Bosch Sensortec - BMI088 - LGA-16 4.5x3.0 mm P0.5

Quantité carte : 1 | Broches et pastilles : contrôle structurel concordant.
Achat : DigiKey France | 828-1082-1-ND
Prix : 5.0700 EUR HT / pièce, tarif quantité 1 | Stock relevé : 0

Ouvrir la fiche fournisseur France (https://www.digikey.fr/fr/products/detail/bosch-sensortec/BMI088/8634936)

Relevé web; stock et prix variables.

PDF technique local : composants/pdf/U9_datasheet.pdf Lien de téléchargement de la fiche technique (https://www.bosch-sensortec.com/media/boschsensortec/downloads/datasheets/bst-bmi088-ds001.pdf)

EMPREINTE / mm | MODÈLE 3D LOCAL

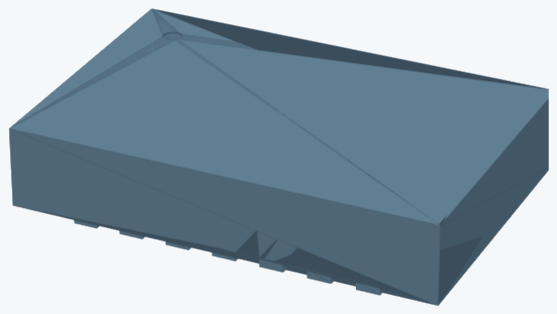
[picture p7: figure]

1 | 2 | 3 | 4 | 5 | 6 | 7

8

15 | 14 | 13 | 12 | 11 | 10 | 9

16

Cuivre ocre / corps bleu / cour dessin gris - vue dessus

3D : KiCad, geometrie generique du boitier

Empreinte : Package_LGA:Bosch_LGA-16_4.5x3mm_P0.5mm_LayoutBorder7x1y_ClockwisePinNumbering
STEP : composants/3d/Bosch_LGA-16_4.5x3mm_P0.5mm_LayoutBorder7x1y_ClockwisePinNumbering.step

Contrôle documentaire : Bosch BMI088 pp.54–55: LGA16 4.5 x 3 mm, pas 0.5; numérotation horaire spécifique Bosch. Empreinte Bosch KiCad conservée; ne pas utiliser LGA16 générique de sens inverse.

Lecture indépendante des fichiers KiCad. Aucun ERC/DRC natif exécuté. | 1

FC_01 / DOSSIER COMPOSANTS / 27.09.2026

# BMI088

SYMBOLE / FC01_Project:SENSORS__BMI088

Repères : U9

SYMBOLE / CORPS ET NUMÉROS DES BROCHES

1
INT2

3

VDD

4

GNDA

5
~{CSB2}

6

GNDIO

7
PS

8
SCK/SCL

9
SDI/SDA

10 SDO2

# 11VDDIO

12 INT3

13 INT4

14 | ~{CSB1}
15 | SDO1

16 INT1

Correspondance complète : verification/PINS.csv | Broches masquées dans le symbole : 2
Rendu vectoriel de la variante utilisée; champs de nomenclature en page précédente. | 2

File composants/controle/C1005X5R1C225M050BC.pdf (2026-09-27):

FC_01 / DOSSIER COMPOSANTS / 27.09.2026

# C1005X5R1C225M050BC

C7 / C10

TDK - 2.2u - 0402 (1005)

Quantité carte : 2 | Broches et pastilles : contrôle structurel concordant.
Achat : Farnell France | 2525017
Prix : 0.1040 EUR HT / pièce, tarif quantité 10 | Stock relevé : 1310

Ouvrir la fiche fournisseur France (https://fr.farnell.com/tdk/c1005x5r1c225m050bc/condensateur-2-2-f-16v-20-x5r/dp/2525017)

Minimum et multiple 10; source indexee il y a 5 mois, stock actuel A RECONFIRMER; disponible jusqu a epuisement.

PDF technique local : composants/pdf/TDK_C.pdf
Lien de téléchargement de la fiche technique (https://product.tdk.com/system/files/dam/doc/product/capacitor/ceramic/mlcc/catalog/mlcc_commercial_general_en.pdf)
EMPREINTE / mm | MODÈLE 3D LOCAL

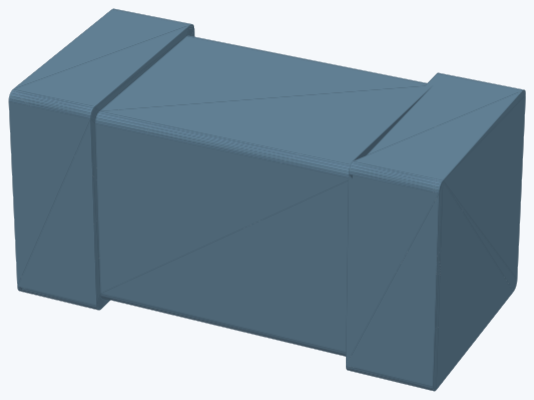
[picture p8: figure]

1 2

Cuivre ocre / corps bleu / cour dessin gris - vue dessus

3D : KiCad, geometrie generique du boitier

Empreinte : Capacitor_SMD:C_0402_1005Metric
STEP : composants/3d/C_0402_1005Metric.step

Contrôle documentaire : TDK C1005: corps 1.0 x 0.5 mm, 2.2 uF 16 V X5R. Deux bornes non polarisées; pads KiCad 0402 conservés.

Lecture indépendante des fichiers KiCad. Aucun ERC/DRC natif exécuté. | 1

FC_01 / DOSSIER COMPOSANTS / 27.09.2026

# C1005X5R1C225M050BC

SYMBOLE / FC01_Project:MCU__C_Small

Repères : C7, C10

SYMBOLE / CORPS ET NUMÉROS DES BROCHES

1

2

Correspondance complète : verification/PINS.csv

Rendu vectoriel de la variante utilisée; champs de nomenclature en page précédente. | 2

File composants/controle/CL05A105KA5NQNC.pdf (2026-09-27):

FC_01 / DOSSIER COMPOSANTS / 27.09.2026

# CL05A105KA5NQNC

C14 / C57

Samsung Electro-Mechanics - 1u - 0402 (1005)

Quantité carte : 2 | Broches et pastilles : contrôle structurel concordant.
Achat : DigiKey France | 1276-1445-1-ND
Prix : 0.1600 EUR HT / pièce, tarif quantité 1 | Stock relevé : 2318576

Ouvrir la fiche fournisseur France (https://www.digikey.fr/fr/products/detail/samsung-electro-mechanics/CL05A105KA5NQNC/3887103)

Relevé web; stock et prix variables.

PDF technique local : composants/pdf/CL05A105KA5NQN.pdf Lien de téléchargement de la fiche technique (https://product.samsungsem.com/part/download.do?masterKey=CL05A105KA5NQN&type=specsheet)

EMPREINTE / mm | MODÈLE 3D LOCAL


1 2

Cuivre ocre / corps bleu / cour dessin gris - vue dessus

3D : KiCad, geometrie generique du boitier

Empreinte : Capacitor_SMD:C_0402_1005Metric
STEP : composants/3d/C_0402_1005Metric.step

Contrôle documentaire : Fiche famille Samsung: code CL05=0402, CL10=0603, CL21=0805; deux bornes non polarisées. Pads KiCad conservés; plan de sérigraphie/stencil à valider avec assembleur.

Lecture indépendante des fichiers KiCad. Aucun ERC/DRC natif exécuté. | 1

SYMBOLE / FC01_Project:MCU__C_Small

Repères : C14

SYMBOLE / CORPS ET NUMÉROS DES BROCHES

1

2

Correspondance complète : verification/PINS.csv

Rendu vectoriel de la variante utilisée; champs de nomenclature en page précédente. | 2

SYMBOLE / FC01_Project:MICRO_SD__C_Small

Repères : C57

SYMBOLE / CORPS ET NUMÉROS DES BROCHES

1

2

Correspondance complète : verification/PINS.csv

Rendu vectoriel de la variante utilisée; champs de nomenclature en page précédente. | 3

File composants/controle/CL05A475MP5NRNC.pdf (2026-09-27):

FC_01 / DOSSIER COMPOSANTS / 27.09.2026

# CL05A475MP5NRNC

C1 / C44 / C45 / C46

Samsung Electro-Mechanics - 4.7u - 0402 (1005)

Quantité carte : 4 | Broches et pastilles : contrôle structurel concordant.
Achat : DigiKey France | 1276-1482-1-ND
Prix : 0.0900 EUR HT / pièce, tarif quantité 1 | Stock relevé : 0

Ouvrir la fiche fournisseur France (https://www.digikey.fr/en/products/detail/samsung-electro-mechanics/CL05A475MP5NRNC/3889568)

Relevé web; stock et prix variables.

PDF technique local : composants/pdf/CL05A475MP5NRN.pdf Lien de téléchargement de la fiche technique (https://product.samsungsem.com/part/download.do?masterKey=CL05A475MP5NRN&type=specsheet)

EMPREINTE / mm | MODÈLE 3D LOCAL


1 2

Cuivre ocre / corps bleu / cour dessin gris - vue dessus

3D : KiCad, geometrie generique du boitier

Empreinte : Capacitor_SMD:C_0402_1005Metric
STEP : composants/3d/C_0402_1005Metric.step

Contrôle documentaire : Fiche famille Samsung: code CL05=0402, CL10=0603, CL21=0805; deux bornes non polarisées. Pads KiCad conservés; plan de sérigraphie/stencil à valider avec assembleur.

Lecture indépendante des fichiers KiCad. Aucun ERC/DRC natif exécuté. | 1

SYMBOLE / FC01_Project:MCU__C_Small

Repères : C1

SYMBOLE / CORPS ET NUMÉROS DES BROCHES

1

2

Correspondance complète : verification/PINS.csv

Rendu vectoriel de la variante utilisée; champs de nomenclature en page précédente. | 2

SYMBOLE / FC01_Project:SENSORS__C_Small

Repères : C44, C45, C46

SYMBOLE / CORPS ET NUMÉROS DES BROCHES

1

2

Correspondance complète : verification/PINS.csv

Rendu vectoriel de la variante utilisée; champs de nomenclature en page précédente. | 3

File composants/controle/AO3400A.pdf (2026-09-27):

FC_01 / DOSSIER COMPOSANTS / 27.09.2026

# AO3400A

Q1

Alpha & Omega Semiconductor - AO3400A - SOT-23-3

Quantité carte : 1 | Broches et pastilles : contrôle structurel concordant.
Achat : DigiKey France | 785-1000-1-ND
Prix : 0.4500 EUR HT / pièce, tarif quantité 1 | Stock relevé : 303659

Ouvrir la fiche fournisseur France (https://www.digikey.fr/fr/products/detail/alpha-omega-semiconductor-inc/AO3400A/1855942)

Relevé web; stock et prix variables.

PDF technique local : composants/pdf/Q1_datasheet.pdf Lien de téléchargement de la fiche technique (https://aosmd.com/res/data_sheets/AO3400A.pdf)

EMPREINTE / mm | MODÈLE 3D LOCAL

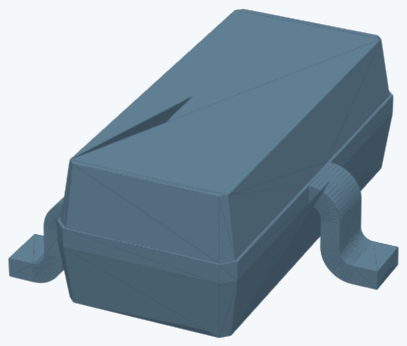
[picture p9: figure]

1

2

3

Cuivre ocre / corps bleu / cour dessin gris - vue dessus

3D : KiCad, geometrie generique du boitier

Empreinte : Package_TO_SOT_SMD:SOT-23
STEP : composants/3d/SOT-23.step

Contrôle documentaire : AOS AO3400A: SOT23, 1Gate 2Source 3Drain; numérotation conservée.

Lecture indépendante des fichiers KiCad. Aucun ERC/DRC natif exécuté. | 1

FC_01 / DOSSIER COMPOSANTS / 27.09.2026

# AO3400A

SYMBOLE / FC01_Project:BUZZER__AO3400A

Repères : Q1

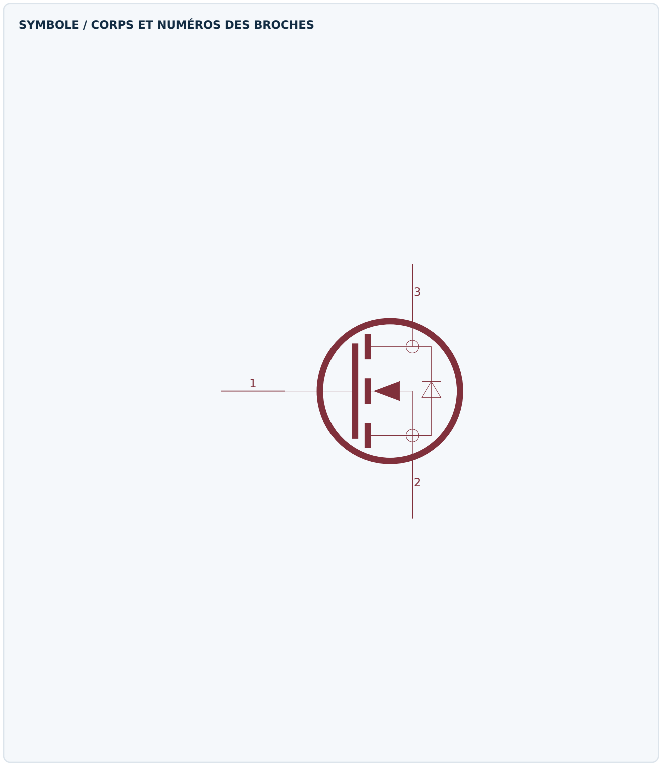
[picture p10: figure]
SYMBOLE / CORPS ET NUMÉROS DES BROCHES

Correspondance complète : verification/PINS.csv

Rendu vectoriel de la variante utilisée; champs de nomenclature en page précédente. | 2

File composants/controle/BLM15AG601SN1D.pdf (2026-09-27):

FC_01 / DOSSIER COMPOSANTS / 27.09.2026

# BLM15AG601SN1D

FB1

Murata Electronics - 600Ω@100MHz - 0402 (1005)

Quantité carte : 1 | Broches et pastilles : contrôle structurel concordant.
Achat : DigiKey France | 490-1006-1-ND
Prix : 0.0900 EUR HT / pièce, tarif quantité 1 | Stock relevé : 1305813

Ouvrir la fiche fournisseur France (https://www.digikey.fr/fr/products/detail/murata-electronics/BLM15AG601SN1D/584217)

Relevé web; stock et prix variables.

PDF technique local : composants/pdf/BLM15.pdf Lien de téléchargement de la fiche technique (https://www.mouser.com/datasheet/2/281/ENFA0018-1218469.pdf)

EMPREINTE / mm | MODÈLE 3D LOCAL


1 2

Cuivre ocre / corps bleu / cour dessin gris - vue dessus

3D : KiCad, geometrie generique du boitier

Empreinte : Inductor_SMD:L_0402_1005Metric
STEP : composants/3d/L_0402_1005Metric.step

Contrôle documentaire : BLM15, boîtier 1005/0402, deux bornes non polarisées. Empreinte KiCad conservée; spécification de commande détaillée à confirmer avant achat.

Lecture indépendante des fichiers KiCad. Aucun ERC/DRC natif exécuté. | 1

FC_01 / DOSSIER COMPOSANTS / 27.09.2026

# BLM15AG601SN1D

SYMBOLE / FC01_Project:MCU__FerriteBead_Small

Repères : FB1

SYMBOLE / CORPS ET NUMÉROS DES BROCHES

1

2

Correspondance complète : verification/PINS.csv

Rendu vectoriel de la variante utilisée; champs de nomenclature en page précédente. | 2

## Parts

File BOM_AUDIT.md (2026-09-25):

# H743_Ardupilot — BOM / EDA audit

Audit date: 2026-09-25

## Scope

Active hierarchical schematic sheets:
- MCU.kicad_sch
- ANALOG_SENS.kicad_sch
- CAN.kicad_sch
- BUZZER.kicad_sch
- MOTORS[1-4].kicad_sch
- UART_I2C.kicad_sch
- POWER.kicad_sch
- SENSORS.kicad_sch
- MICRO_SD.kicad_sch

145 placed components were reviewed.

## Metadata added

Each purchasable component now carries, when applicable:
- Manufacturer
- MPN
- Package
- Datasheet
- DigiKey Part Number
- DigiKey URL
- DigiKey Specs
- DigiKey Unit Price EUR
- DigiKey Price Qty
- Price Checked
- DigiKey Status
- Footprint Audit
- Library Audit

## Main corrections

- Sensor power-domain architecture: onboard sensor VDD rails use `+3V3_SENS`, while VDDIO rails use `+3V3_MCU` so digital I/O levels are referenced to the MCU logic rail (ICM-45686, LSM6DSV16X, BMI088, BMP581 and DPS368).

- Incorrect resistor MPN/value mappings were replaced by value-correct YAGEO RC0402-family parts.
- Logic-domain 100 nF capacitors were normalized to 16 V X7R parts.
- POWER-sheet 100 nF capacitors were normalized to 50 V X7R parts.
- 22 µF / 0805 power capacitors were normalized to active 25 V X5R metadata.
- CAN U3 metadata now matches the actual NXP TJA1051TK/3,118 device and records DigiKey Last-Time-Buy status.
- D5 metadata remains normalized to active 1N5819HW-7-F, 40 V / 1 A / SOD-123. D4 was subsequently upgraded to PMEG4030ER,115 (40 V / 3 A / SOD-123W).
- BMP581 uses project-local footprint alias H743_Custom:QFN10_BMP581_BOS.
- A project fp-lib-table was added for extralib/footprints.pretty.
- BMP581 symbol-library datasheet and footprint fields were corrected.
- BOM_DigiKey.csv was added to the repository.

## Remaining footprint / mechanical checks

### Blocking
- J1/J2/J3/J5/J6/J7/J8/J9: resolved as project-local 1x4 solder-pad arrays, 2.54 mm pitch, 1.00 x 1.00 mm square SMD pads, no holes and no paste.
- J4: resolved as project-local 1x6 solder-pad array, 2.54 mm pitch, 1.00 x 1.00 mm square SMD pads, no holes and no paste.
- J12: resolved as project-local 1x3 solder-pad array, 2.54 mm pitch, 1.00 x 1.00 mm square SMD pads, no holes and no paste.

### Needs final land-pattern verification
- POWER U12 LMR43620R5RPER: current EasyEDA footprint name is 2.1 x 2.1 mm; compare pad geometry to TI RPE land pattern.
- MICRO_SD J10 TF-028-H265: compare EasyEDA footprint with HANBO mechanical drawing.
- BUZZER U10 ZX-SH1.0-3PWT: compare supplier drawing with EasyEDA footprint.
- MCU D1 RGB LED: compare supplier drawing with EasyEDA footprint.
- MCU JP1: footprint library `_pico` is not stored in this repository.
- Top-level H1-H4 mounting-hole footprints also reference the unresolved `_pico` library.
- MCU TP1-TP4 still have no PCB footprint assigned.
- MCU TP1-TP4: test-point symbols currently have no schematic footprint assigned.

## Price coverage

The unit-price field exists for all rows. Exact qty-1 prices were populated where they could be verified from DigiKey during this audit.

24 rows intentionally remain without a numeric price because an exact current DigiKey qty-1 price could not be independently verified:
- 3 x 220 ohm resistors RC0402FR-07220RL
- 18 x 200 ohm resistors RC0402FR-07200RL
- 1 x 12.4 kohm resistor RC0402FR-0712K4L
- 2 x Coilcraft XGL4030-332MEC inductors (3.3 µH)

No price was invented for these rows.

## Tool limitation

A full KiCad ERC/DRC was not run because kicad-cli is not installed in the execution environment.

## XGL4030 inductor / footprint correction

- 6S ripple recheck at 25.2 V and ~2 MHz drove the change from 2.2 µH to 3.3 µH.
- XGL4020-332MEC was rejected for the 9 V / 3 A rail because its saturation margin was too small; XGL4030-332MEC provides higher saturation-current margin.

- L1 and L2 use `H743_Custom:L_Coilcraft_XGL4030` with Coilcraft XGL4030-332MEC, 3.3 µH.
- XGL4030 recommended land pattern uses 0.98 x 3.40 mm pads with centers at +/-1.185 mm; project-local footprint updated accordingly.
- Pad 1 is the marked/start terminal; in the current POWER schematic, L1.1 = SW_5V and L2.1 = SW_9V, which follows Coilcraft's recommendation to connect the high-dv/dt node to the start/short lead for lowest EMI.

## D4 5 V OR-ing diode update

- D4 changed from 1N5819HW-7-F (1 A) to **Nexperia PMEG4030ER,115**.
- Rating: 40 V, 3 A average forward current, Vf max 0.54 V @ 3 A.
- Package: **CFP3 / SOD-123W**; schematic footprint: `Diode_SMD:Nexperia_CFP3_SOD-123W`. This is not the same land pattern as SOD-123. The schematic is corrected; the current legacy PCB file still contains the old D4 SOD-123 footprint and must be synchronized before routing.
- DigiKey P/N: `1727-5313-1-ND`; qty-1 price recorded at 0.51 EUR on 2026-09-25.
- DigiKey CT reference for D4: **1727-5313-1-ND**; verified product page: PMEG4030ER,115 / 40 V / 3 A / SOD-123W.
- D5 remains 1N5819HW-7-F on the USB branch.

## Matek-style solder-pad arrays

- Project-local footprints added:
  - `H743_Custom:SolderPadArray_1x03_P2.54mm_1x1mm`
  - `H743_Custom:SolderPadArray_1x04_P2.54mm_1x1mm`
  - `H743_Custom:SolderPadArray_1x06_P2.54mm_1x1mm`
- Copper pads are 1.00 x 1.00 mm square on 2.54 mm centers.
- These are SMD solder pads only: no drill and no paste aperture. The footprint can be flipped to the PCB bottom side when required.

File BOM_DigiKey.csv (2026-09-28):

Sheet | Reference | Value | Manufacturer | MPN | Package | Footprint | Datasheet | DigiKey_Part_Number | DigiKey_URL | DigiKey_Specs | Unit_Price_EUR | Price_Qty | Price_Checked | DigiKey_Status | Footprint_Audit | Library_Audit | Supplier | Supplier_Order_Code | Supplier_URL
MCU.kicad_sch | C1 | 4.7u | Samsung Electro-Mechanics | CL05A475MP5NRNC | 0402 (1005) | Capacitor_SMD:C_0402_1005Metric | ${KIPRJMOD}/composants/pdf/CL05A475MP5NRN.pdf | 1276-1482-1-ND | https://www.digikey.fr/en/products/detail/samsung-electro-mechanics/CL05A475MP5NRNC/3889568 | 4.7 µF ±20%, 10 V, X5R, 0402 | 0.09 | 1 | 2026-09-27 | Stock 0 | Voir composants/catalogue.json et verification/REPORT.md | Voir composants/README.md | DigiKey France | 1276-1482-1-ND | https://www.digikey.fr/en/products/detail/samsung-electro-mechanics/CL05A475MP5NRNC/3889568
MCU.kicad_sch | C2 | 100n | Samsung Electro-Mechanics | CL05B104KO5NNNC | 0402 (1005) | Capacitor_SMD:C_0402_1005Metric | ${KIPRJMOD}/composants/pdf/CL05B104KO5NNN.pdf | 1276-1001-1-ND | https://www.digikey.fr/fr/products/detail/samsung-electro-mechanics/CL05B104KO5NNNC/3889087 | 100 nF ±10%, 16 V, X7R, 0402 | 0.09 | 1 | 2026-09-27 | Stock 103052 | Voir composants/catalogue.json et verification/REPORT.md | Voir composants/README.md | DigiKey France | 1276-1001-1-ND | https://www.digikey.fr/fr/products/detail/samsung-electro-mechanics/CL05B104KO5NNNC/3889087
MCU.kicad_sch | C3 | 100n | Samsung Electro-Mechanics | CL05B104KO5NNNC | 0402 (1005) | Capacitor_SMD:C_0402_1005Metric | ${KIPRJMOD}/composants/pdf/CL05B104KO5NNN.pdf | 1276-1001-1-ND | https://www.digikey.fr/fr/products/detail/samsung-electro-mechanics/CL05B104KO5NNNC/3889087 | 100 nF ±10%, 16 V, X7R, 0402 | 0.09 | 1 | 2026-09-27 | Stock 103052 | Voir composants/catalogue.json et verification/REPORT.md | Voir composants/README.md | DigiKey France | 1276-1001-1-ND | https://www.digikey.fr/fr/products/detail/samsung-electro-mechanics/CL05B104KO5NNNC/3889087
MCU.kicad_sch | C4 | 100n | Samsung Electro-Mechanics | CL05B104KO5NNNC | 0402 (1005) | Capacitor_SMD:C_0402_1005Metric | ${KIPRJMOD}/composants/pdf/CL05B104KO5NNN.pdf | 1276-1001-1-ND | https://www.digikey.fr/fr/products/detail/samsung-electro-mechanics/CL05B104KO5NNNC/3889087 | 100 nF ±10%, 16 V, X7R, 0402 | 0.09 | 1 | 2026-09-27 | Stock 103052 | Voir composants/catalogue.json et verification/REPORT.md | Voir composants/README.md | DigiKey France | 1276-1001-1-ND | https://www.digikey.fr/fr/products/detail/samsung-electro-mechanics/CL05B104KO5NNNC/3889087
MCU.kicad_sch | C5 | 100n | Samsung Electro-Mechanics | CL05B104KO5NNNC | 0402 (1005) | Capacitor_SMD:C_0402_1005Metric | ${KIPRJMOD}/composants/pdf/CL05B104KO5NNN.pdf | 1276-1001-1-ND | https://www.digikey.fr/fr/products/detail/samsung-electro-mechanics/CL05B104KO5NNNC/3889087 | 100 nF ±10%, 16 V, X7R, 0402 | 0.09 | 1 | 2026-09-27 | Stock 103052 | Voir composants/catalogue.json et verification/REPORT.md | Voir composants/README.md | DigiKey France | 1276-1001-1-ND | https://www.digikey.fr/fr/products/detail/samsung-electro-mechanics/CL05B104KO5NNNC/3889087
MCU.kicad_sch | C6 | 100n | Samsung Electro-Mechanics | CL05B104KO5NNNC | 0402 (1005) | Capacitor_SMD:C_0402_1005Metric | ${KIPRJMOD}/composants/pdf/CL05B104KO5NNN.pdf | 1276-1001-1-ND | https://www.digikey.fr/fr/products/detail/samsung-electro-mechanics/CL05B104KO5NNNC/3889087 | 100 nF ±10%, 16 V, X7R, 0402 | 0.09 | 1 | 2026-09-27 | Stock 103052 | Voir composants/catalogue.json et verification/REPORT.md | Voir composants/README.md | DigiKey France | 1276-1001-1-ND | https://www.digikey.fr/fr/products/detail/samsung-electro-mechanics/CL05B104KO5NNNC/3889087
MCU.kicad_sch | C7 | 2.2u | TDK | C1005X5R1C225M050BC | 0402 (1005) | Capacitor_SMD:C_0402_1005Metric | ${KIPRJMOD}/composants/pdf/TDK_C.pdf |  |  | 2.2 µF ±20%, 16 V, X5R, 0402 | 0.104 | 10 | 2026-09-27 | Voir composants/BOM_FR.csv | Voir composants/catalogue.json et verification/REPORT.md | Voir composants/README.md | Farnell France | 2525017 | https://fr.farnell.com/tdk/c1005x5r1c225m050bc/condensateur-2-2-f-16v-20-x5r/dp/2525017
MCU.kicad_sch | C8 | 100n | Samsung Electro-Mechanics | CL05B104KO5NNNC | 0402 (1005) | Capacitor_SMD:C_0402_1005Metric | ${KIPRJMOD}/composants/pdf/CL05B104KO5NNN.pdf | 1276-1001-1-ND | https://www.digikey.fr/fr/products/detail/samsung-electro-mechanics/CL05B104KO5NNNC/3889087 | 100 nF ±10%, 16 V, X7R, 0402 | 0.09 | 1 | 2026-09-27 | Stock 103052 | Voir composants/catalogue.json et verification/REPORT.md | Voir composants/README.md | DigiKey France | 1276-1001-1-ND | https://www.digikey.fr/fr/products/detail/samsung-electro-mechanics/CL05B104KO5NNNC/3889087
MCU.kicad_sch | C9 | 100n | Samsung Electro-Mechanics | CL05B104KO5NNNC | 0402 (1005) | Capacitor_SMD:C_0402_1005Metric | ${KIPRJMOD}/composants/pdf/CL05B104KO5NNN.pdf | 1276-1001-1-ND | https://www.digikey.fr/fr/products/detail/samsung-electro-mechanics/CL05B104KO5NNNC/3889087 | 100 nF ±10%, 16 V, X7R, 0402 | 0.09 | 1 | 2026-09-27 | Stock 103052 | Voir composants/catalogue.json et verification/REPORT.md | Voir composants/README.md | DigiKey France | 1276-1001-1-ND | https://www.digikey.fr/fr/products/detail/samsung-electro-mechanics/CL05B104KO5NNNC/3889087
MCU.kicad_sch | C10 | 2.2u | TDK | C1005X5R1C225M050BC | 0402 (1005) | Capacitor_SMD:C_0402_1005Metric | ${KIPRJMOD}/composants/pdf/TDK_C.pdf |  |  | 2.2 µF ±20%, 16 V, X5R, 0402 | 0.104 | 10 | 2026-09-27 | Voir composants/BOM_FR.csv | Voir composants/catalogue.json et verification/REPORT.md | Voir composants/README.md | Farnell France | 2525017 | https://fr.farnell.com/tdk/c1005x5r1c225m050bc/condensateur-2-2-f-16v-20-x5r/dp/2525017
MCU.kicad_sch | C11 | 100n | Samsung Electro-Mechanics | CL05B104KO5NNNC | 0402 (1005) | Capacitor_SMD:C_0402_1005Metric | ${KIPRJMOD}/composants/pdf/CL05B104KO5NNN.pdf | 1276-1001-1-ND | https://www.digikey.fr/fr/products/detail/samsung-electro-mechanics/CL05B104KO5NNNC/3889087 | 100 nF ±10%, 16 V, X7R, 0402 | 0.09 | 1 | 2026-09-27 | Stock 103052 | Voir composants/catalogue.json et verification/REPORT.md | Voir composants/README.md | DigiKey France | 1276-1001-1-ND | https://www.digikey.fr/fr/products/detail/samsung-electro-mechanics/CL05B104KO5NNNC/3889087
MCU.kicad_sch | C12 | 100n | Samsung Electro-Mechanics | CL05B104KO5NNNC | 0402 (1005) | Capacitor_SMD:C_0402_1005Metric | ${KIPRJMOD}/composants/pdf/CL05B104KO5NNN.pdf | 1276-1001-1-ND | https://www.digikey.fr/fr/products/detail/samsung-electro-mechanics/CL05B104KO5NNNC/3889087 | 100 nF ±10%, 16 V, X7R, 0402 | 0.09 | 1 | 2026-09-27 | Stock 103052 | Voir composants/catalogue.json et verification/REPORT.md | Voir composants/README.md | DigiKey France | 1276-1001-1-ND | https://www.digikey.fr/fr/products/detail/samsung-electro-mechanics/CL05B104KO5NNNC/3889087
MCU.kicad_sch | C14 | 1u | Samsung Electro-Mechanics | CL05A105KA5NQNC | 0402 (1005) | Capacitor_SMD:C_0402_1005Metric | ${KIPRJMOD}/composants/pdf/CL05A105KA5NQN.pdf | 1276-1445-1-ND | https://www.digikey.fr/fr/products/detail/samsung-electro-mechanics/CL05A105KA5NQNC/3887103 | 1 µF ±10%, 25 V, X5R, 0402 | 0.16 | 1 | 2026-09-27 | Stock 2318576 | Voir composants/catalogue.json et verification/REPORT.md | Voir composants/README.md | DigiKey France | 1276-1445-1-ND | https://www.digikey.fr/fr/products/detail/samsung-electro-mechanics/CL05A105KA5NQNC/3887103
MCU.kicad_sch | C15 | 100n | Samsung Electro-Mechanics | CL05B104KO5NNNC | 0402 (1005) | Capacitor_SMD:C_0402_1005Metric | ${KIPRJMOD}/composants/pdf/CL05B104KO5NNN.pdf | 1276-1001-1-ND | https://www.digikey.fr/fr/products/detail/samsung-electro-mechanics/CL05B104KO5NNNC/3889087 | 100 nF ±10%, 16 V, X7R, 0402 | 0.09 | 1 | 2026-09-27 | Stock 103052 | Voir composants/catalogue.json et verification/REPORT.md | Voir composants/README.md | DigiKey France | 1276-1001-1-ND | https://www.digikey.fr/fr/products/detail/samsung-electro-mechanics/CL05B104KO5NNNC/3889087
POWER.kicad_sch | C16 | 10u | Murata Electronics | GRM21BR61H106KE43L | 0805 (2012) | Capacitor_SMD:C_0805_2012Metric | ${KIPRJMOD}/composants/pdf/GRM21.pdf | 490-18663-1-ND | https://www.digikey.fr/en/products/detail/murata-electronics/GRM21BR61H106KE43L/10326316 | 10 µF ±10%, 50 V, X5R, 0805 | 0.28 | 1 | 2026-09-27 | Stock 0 | Voir composants/catalogue.json et verification/REPORT.md | Voir composants/README.md | DigiKey France | 490-18663-1-ND | https://www.digikey.fr/en/products/detail/murata-electronics/GRM21BR61H106KE43L/10326316
POWER.kicad_sch | C17 | 100n | Murata Electronics | GCM155R71H104KE02D | 0402 (1005 Metric) | Capacitor_SMD:C_0402_1005Metric | ${KIPRJMOD}/composants/pdf/GCM155.pdf | 490-10672-1-ND | https://www.digikey.fr/fr/products/detail/murata-electronics/GCM155R71H104KE02D/5251433 | 100 nF ±10%, 50 V, X7R, 0402 (1005) | 0.09 | 1 | 2026-09-27 | Stock 16172272 | Voir composants/catalogue.json et verification/REPORT.md | Voir composants/README.md | DigiKey France | 490-10672-1-ND | https://www.digikey.fr/fr/products/detail/murata-electronics/GCM155R71H104KE02D/5251433
POWER.kicad_sch | C18 | 10u | Murata Electronics | GRM21BR61H106KE43L | 0805 (2012) | Capacitor_SMD:C_0805_2012Metric | ${KIPRJMOD}/composants/pdf/GRM21.pdf | 490-18663-1-ND | https://www.digikey.fr/en/products/detail/murata-electronics/GRM21BR61H106KE43L/10326316 | 10 µF ±10%, 50 V, X5R, 0805 | 0.28 | 1 | 2026-09-27 | Stock 0 | Voir composants/catalogue.json et verification/REPORT.md | Voir composants/README.md | DigiKey France | 490-18663-1-ND | https://www.digikey.fr/en/products/detail/murata-electronics/GRM21BR61H106KE43L/10326316
POWER.kicad_sch | C19 | 100n | Murata Electronics | GCM155R71H104KE02D | 0402 (1005 Metric) | Capacitor_SMD:C_0402_1005Metric | ${KIPRJMOD}/composants/pdf/GCM155.pdf | 490-10672-1-ND | https://www.digikey.fr/fr/products/detail/murata-electronics/GCM155R71H104KE02D/5251433 | 100 nF ±10%, 50 V, X7R, 0402 (1005) | 0.09 | 1 | 2026-09-27 | Stock 16172272 | Voir composants/catalogue.json et verification/REPORT.md | Voir composants/README.md | DigiKey France | 490-10672-1-ND | https://www.digikey.fr/fr/products/detail/murata-electronics/GCM155R71H104KE02D/5251433
POWER.kicad_sch | C20 | 1u | Samsung Electro-Mechanics | CL10A105KB8NNNC | 0603 (1608) | Capacitor_SMD:C_0603_1608Metric | ${KIPRJMOD}/composants/pdf/CL10A105KB8NNN.pdf | 1276-1860-1-ND | https://www.digikey.fr/fr/products/detail/samsung-electro-mechanics/CL10A105KB8NNNC/3887518 | 1 µF ±10%, 50 V, X5R, 0603 | 0.12 | 1 | 2026-09-27 | Stock 1025442 | Voir composants/catalogue.json et verification/REPORT.md | Voir composants/README.md | DigiKey France | 1276-1860-1-ND | https://www.digikey.fr/fr/products/detail/samsung-electro-mechanics/CL10A105KB8NNNC/3887518
POWER.kicad_sch | C21 | 100n | Murata Electronics | GCM155R71H104KE02D | 0402 (1005 Metric) | Capacitor_SMD:C_0402_1005Metric | ${KIPRJMOD}/composants/pdf/GCM155.pdf | 490-10672-1-ND | https://www.digikey.fr/fr/products/detail/murata-electronics/GCM155R71H104KE02D/5251433 | 100 nF ±10%, 50 V, X7R, 0402 (1005) | 0.09 | 1 | 2026-09-27 | Stock 16172272 | Voir composants/catalogue.json et verification/REPORT.md | Voir composants/README.md | DigiKey France | 490-10672-1-ND | https://www.digikey.fr/fr/products/detail/murata-electronics/GCM155R71H104KE02D/5251433
POWER.kicad_sch | C22 | 100n | Murata Electronics | GCM155R71H104KE02D | 0402 (1005 Metric) | Capacitor_SMD:C_0402_1005Metric | ${KIPRJMOD}/composants/pdf/GCM155.pdf | 490-10672-1-ND | https://www.digikey.fr/fr/products/detail/murata-electronics/GCM155R71H104KE02D/5251433 | 100 nF ±10%, 50 V, X7R, 0402 (1005) | 0.09 | 1 | 2026-09-27 | Stock 16172272 | Voir composants/catalogue.json et verification/REPORT.md | Voir composants/README.md | DigiKey France | 490-10672-1-ND | https://www.digikey.fr/fr/products/detail/murata-electronics/GCM155R71H104KE02D/5251433
POWER.kicad_sch | C23 | 22u | Samsung Electro-Mechanics | CL21A226MAYNNNE | 0805 (2012), max H 1.45 mm | Capacitor_SMD:C_0805_2012Metric | ${KIPRJMOD}/composants/pdf/CL21A226MAYNNN.pdf | 1276-CL21A226MAYNNNECT-ND | https://www.digikey.fr/fr/products/detail/samsung-electro-mechanics/CL21A226MAYNNNE/10479857 | 22 µF ±20%, 25 V, X5R, 0805 | 0.27 | 1 | 2026-09-27 | Stock 0 | Voir composants/catalogue.json et verification/REPORT.md | Voir composants/README.md | DigiKey France | 1276-CL21A226MAYNNNECT-ND | https://www.digikey.fr/fr/products/detail/samsung-electro-mechanics/CL21A226MAYNNNE/10479857
POWER.kicad_sch | C24 | 22u | Samsung Electro-Mechanics | CL21A226MAYNNNE | 0805 (2012), max H 1.45 mm | Capacitor_SMD:C_0805_2012Metric | ${KIPRJMOD}/composants/pdf/CL21A226MAYNNN.pdf | 1276-CL21A226MAYNNNECT-ND | https://www.digikey.fr/fr/products/detail/samsung-electro-mechanics/CL21A226MAYNNNE/10479857 | 22 µF ±20%, 25 V, X5R, 0805 | 0.27 | 1 | 2026-09-27 | Stock 0 | Voir composants/catalogue.json et verification/REPORT.md | Voir composants/README.md | DigiKey France | 1276-CL21A226MAYNNNECT-ND | https://www.digikey.fr/fr/products/detail/samsung-electro-mechanics/CL21A226MAYNNNE/10479857
POWER.kicad_sch | C25 | 100n | Murata Electronics | GCM155R71H104KE02D | 0402 (1005 Metric) | Capacitor_SMD:C_0402_1005Metric | ${KIPRJMOD}/composants/pdf/GCM155.pdf | 490-10672-1-ND | https://www.digikey.fr/fr/products/detail/murata-electronics/GCM155R71H104KE02D/5251433 | 100 nF ±10%, 50 V, X7R, 0402 (1005) | 0.09 | 1 | 2026-09-27 | Stock 16172272 | Voir composants/catalogue.json et verification/REPORT.md | Voir composants/README.md | DigiKey France | 490-10672-1-ND | https://www.digikey.fr/fr/products/detail/murata-electronics/GCM155R71H104KE02D/5251433
POWER.kicad_sch | C26 | 22u | Samsung Electro-Mechanics | CL21A226MAYNNNE | 0805 (2012), max H 1.45 mm | Capacitor_SMD:C_0805_2012Metric | ${KIPRJMOD}/composants/pdf/CL21A226MAYNNN.pdf | 1276-CL21A226MAYNNNECT-ND | https://www.digikey.fr/fr/products/detail/samsung-electro-mechanics/CL21A226MAYNNNE/10479857 | 22 µF ±20%, 25 V, X5R, 0805 | 0.27 | 1 | 2026-09-27 | Stock 0 | Voir composants/catalogue.json et verification/REPORT.md | Voir composants/README.md | DigiKey France | 1276-CL21A226MAYNNNECT-ND | https://www.digikey.fr/fr/products/detail/samsung-electro-mechanics/CL21A226MAYNNNE/10479857
POWER.kicad_sch | C27 | 22u | Samsung Electro-Mechanics | CL21A226MAYNNNE | 0805 (2012), max H 1.45 mm | Capacitor_SMD:C_0805_2012Metric | ${KIPRJMOD}/composants/pdf/CL21A226MAYNNN.pdf | 1276-CL21A226MAYNNNECT-ND | https://www.digikey.fr/fr/products/detail/samsung-electro-mechanics/CL21A226MAYNNNE/10479857 | 22 µF ±20%, 25 V, X5R, 0805 | 0.27 | 1 | 2026-09-27 | Stock 0 | Voir composants/catalogue.json et verification/REPORT.md | Voir composants/README.md | DigiKey France | 1276-CL21A226MAYNNNECT-ND | https://www.digikey.fr/fr/products/detail/samsung-electro-mechanics/CL21A226MAYNNNE/10479857
POWER.kicad_sch | C28 | 100n | Murata Electronics | GCM155R71H104KE02D | 0402 (1005 Metric) | Capacitor_SMD:C_0402_1005Metric | ${KIPRJMOD}/composants/pdf/GCM155.pdf | 490-10672-1-ND | https://www.digikey.fr/fr/products/detail/murata-electronics/GCM155R71H104KE02D/5251433 | 100 nF ±10%, 50 V, X7R, 0402 (1005) | 0.09 | 1 | 2026-09-27 | Stock 16172272 | Voir composants/catalogue.json et verification/REPORT.md | Voir composants/README.md | DigiKey France | 490-10672-1-ND | https://www.digikey.fr/fr/products/detail/murata-electronics/GCM155R71H104KE02D/5251433
POWER.kicad_sch | C29 | 4.7u | Samsung Electro-Mechanics | CL10A475KO8NNNC | 0603 (1608) | Capacitor_SMD:C_0603_1608Metric | ${KIPRJMOD}/composants/pdf/CL10A475KO8NNN.pdf | 1276-1784-1-ND | https://www.digikey.fr/fr/products/detail/samsung-electro-mechanics/CL10A475KO8NNNC/3887442 | 4.7 µF ±10%, 16 V, X5R, 0603 | 0.12 | 1 | 2026-09-27 | Stock 1213 | Voir composants/catalogue.json et verification/REPORT.md | Voir composants/README.md | DigiKey France | 1276-1784-1-ND | https://www.digikey.fr/fr/products/detail/samsung-electro-mechanics/CL10A475KO8NNNC/3887442
POWER.kicad_sch | C30 | 4.7u | Samsung Electro-Mechanics | CL10A475KO8NNNC | 0603 (1608) | Capacitor_SMD:C_0603_1608Metric | ${KIPRJMOD}/composants/pdf/CL10A475KO8NNN.pdf | 1276-1784-1-ND | https://www.digikey.fr/fr/products/detail/samsung-electro-mechanics/CL10A475KO8NNNC/3887442 | 4.7 µF ±10%, 16 V, X5R, 0603 | 0.12 | 1 | 2026-09-27 | Stock 1213 | Voir composants/catalogue.json et verification/REPORT.md | Voir composants/README.md | DigiKey France | 1276-1784-1-ND | https://www.digikey.fr/fr/products/detail/samsung-electro-mechanics/CL10A475KO8NNNC/3887442
POWER.kicad_sch | C31 | 4.7u | Samsung Electro-Mechanics | CL10A475KO8NNNC | 0603 (1608) | Capacitor_SMD:C_0603_1608Metric | ${KIPRJMOD}/composants/pdf/CL10A475KO8NNN.pdf | 1276-1784-1-ND | https://www.digikey.fr/fr/products/detail/samsung-electro-mechanics/CL10A475KO8NNNC/3887442 | 4.7 µF ±10%, 16 V, X5R, 0603 | 0.12 | 1 | 2026-09-27 | Stock 1213 | Voir composants/catalogue.json et verification/REPORT.md | Voir composants/README.md | DigiKey France | 1276-1784-1-ND | https://www.digikey.fr/fr/products/detail/samsung-electro-mechanics/CL10A475KO8NNNC/3887442
POWER.kicad_sch | C32 | 4.7u | Samsung Electro-Mechanics | CL10A475KO8NNNC | 0603 (1608) | Capacitor_SMD:C_0603_1608Metric | ${KIPRJMOD}/composants/pdf/CL10A475KO8NNN.pdf | 1276-1784-1-ND | https://www.digikey.fr/fr/products/detail/samsung-electro-mechanics/CL10A475KO8NNNC/3887442 | 4.7 µF ±10%, 16 V, X5R, 0603 | 0.12 | 1 | 2026-09-27 | Stock 1213 | Voir composants/catalogue.json et verification/REPORT.md | Voir composants/README.md | DigiKey France | 1276-1784-1-ND | https://www.digikey.fr/fr/products/detail/samsung-electro-mechanics/CL10A475KO8NNNC/3887442
ANALOG_SENS.kicad_sch | C33 | 100n | Samsung Electro-Mechanics | CL05B104KO5NNNC | 0402 (1005) | Capacitor_SMD:C_0402_1005Metric | ${KIPRJMOD}/composants/pdf/CL05B104KO5NNN.pdf | 1276-1001-1-ND | https://www.digikey.fr/fr/products/detail/samsung-electro-mechanics/CL05B104KO5NNNC/3889087 | 100 nF ±10%, 16 V, X7R, 0402 | 0.09 | 1 | 2026-09-27 | Stock 103052 | Voir composants/catalogue.json et verification/REPORT.md | Voir composants/README.md | DigiKey France | 1276-1001-1-ND | https://www.digikey.fr/fr/products/detail/samsung-electro-mechanics/CL05B104KO5NNNC/3889087
ANALOG_SENS.kicad_sch | C34 | 100n | Samsung Electro-Mechanics | CL05B104KO5NNNC | 0402 (1005) | Capacitor_SMD:C_0402_1005Metric | ${KIPRJMOD}/composants/pdf/CL05B104KO5NNN.pdf | 1276-1001-1-ND | https://www.digikey.fr/fr/products/detail/samsung-electro-mechanics/CL05B104KO5NNNC/3889087 | 100 nF ±10%, 16 V, X7R, 0402 | 0.09 | 1 | 2026-09-27 | Stock 103052 | Voir composants/catalogue.json et verification/REPORT.md | Voir composants/README.md | DigiKey France | 1276-1001-1-ND | https://www.digikey.fr/fr/products/detail/samsung-electro-mechanics/CL05B104KO5NNNC/3889087
ANALOG_SENS.kicad_sch | C35 | 100n | Samsung Electro-Mechanics | CL05B104KO5NNNC | 0402 (1005) | Capacitor_SMD:C_0402_1005Metric | ${KIPRJMOD}/composants/pdf/CL05B104KO5NNN.pdf | 1276-1001-1-ND | https://www.digikey.fr/fr/products/detail/samsung-electro-mechanics/CL05B104KO5NNNC/3889087 | 100 nF ±10%, 16 V, X7R, 0402 | 0.09 | 1 | 2026-09-27 | Stock 103052 | Voir composants/catalogue.json et verification/REPORT.md | Voir composants/README.md | DigiKey France | 1276-1001-1-ND | https://www.digikey.fr/fr/products/detail/samsung-electro-mechanics/CL05B104KO5NNNC/3889087
UART_I2C.kicad_sch | C36 | 100n | Samsung Electro-Mechanics | CL05B104KO5NNNC | 0402 (1005) | Capacitor_SMD:C_0402_1005Metric | ${KIPRJMOD}/composants/pdf/CL05B104KO5NNN.pdf | 1276-1001-1-ND | https://www.digikey.fr/fr/products/detail/samsung-electro-mechanics/CL05B104KO5NNNC/3889087 | 100 nF ±10%, 16 V, X7R, 0402 | 0.09 | 1 | 2026-09-27 | Stock 103052 | Voir composants/catalogue.json et verification/REPORT.md | Voir composants/README.md | DigiKey France | 1276-1001-1-ND | https://www.digikey.fr/fr/products/detail/samsung-electro-mechanics/CL05B104KO5NNNC/3889087
UART_I2C.kicad_sch | C37 | 10u | Murata Electronics | GRM21BR61H106KE43L | 0805 (2012) | Capacitor_SMD:C_0805_2012Metric | ${KIPRJMOD}/composants/pdf/GRM21.pdf | 490-18663-1-ND | https://www.digikey.fr/en/products/detail/murata-electronics/GRM21BR61H106KE43L/10326316 | 10 µF ±10%, 50 V, X5R, 0805 | 0.28 | 1 | 2026-09-27 | Stock 0 | Voir composants/catalogue.json et verification/REPORT.md | Voir composants/README.md | DigiKey France | 490-18663-1-ND | https://www.digikey.fr/en/products/detail/murata-electronics/GRM21BR61H106KE43L/10326316
UART_I2C.kicad_sch | C38 | 100n | Samsung Electro-Mechanics | CL05B104KO5NNNC | 0402 (1005) | Capacitor_SMD:C_0402_1005Metric | ${KIPRJMOD}/composants/pdf/CL05B104KO5NNN.pdf | 1276-1001-1-ND | https://www.digikey.fr/fr/products/detail/samsung-electro-mechanics/CL05B104KO5NNNC/3889087 | 100 nF ±10%, 16 V, X7R, 0402 | 0.09 | 1 | 2026-09-27 | Stock 103052 | Voir composants/catalogue.json et verification/REPORT.md | Voir composants/README.md | DigiKey France | 1276-1001-1-ND | https://www.digikey.fr/fr/products/detail/samsung-electro-mechanics/CL05B104KO5NNNC/3889087
UART_I2C.kicad_sch | C39 | 100n | Samsung Electro-Mechanics | CL05B104KO5NNNC | 0402 (1005) | Capacitor_SMD:C_0402_1005Metric | ${KIPRJMOD}/composants/pdf/CL05B104KO5NNN.pdf | 1276-1001-1-ND | https://www.digikey.fr/fr/products/detail/samsung-electro-mechanics/CL05B104KO5NNNC/3889087 | 100 nF ±10%, 16 V, X7R, 0402 | 0.09 | 1 | 2026-09-27 | Stock 103052 | Voir composants/catalogue.json et verification/REPORT.md | Voir composants/README.md | DigiKey France | 1276-1001-1-ND | https://www.digikey.fr/fr/products/detail/samsung-electro-mechanics/CL05B104KO5NNNC/3889087
UART_I2C.kicad_sch | C40 | 100n | Samsung Electro-Mechanics | CL05B104KO5NNNC | 0402 (1005) | Capacitor_SMD:C_0402_1005Metric | ${KIPRJMOD}/composants/pdf/CL05B104KO5NNN.pdf | 1276-1001-1-ND | https://www.digikey.fr/fr/products/detail/samsung-electro-mechanics/CL05B104KO5NNNC/3889087 | 100 nF ±10%, 16 V, X7R, 0402 | 0.09 | 1 | 2026-09-27 | Stock 103052 | Voir composants/catalogue.json et verification/REPORT.md | Voir composants/README.md | DigiKey France | 1276-1001-1-ND | https://www.digikey.fr/fr/products/detail/samsung-electro-mechanics/CL05B104KO5NNNC/3889087
UART_I2C.kicad_sch | C41 | 100n | Samsung Electro-Mechanics | CL05B104KO5NNNC | 0402 (1005) | Capacitor_SMD:C_0402_1005Metric | ${KIPRJMOD}/composants/pdf/CL05B104KO5NNN.pdf | 1276-1001-1-ND | https://www.digikey.fr/fr/products/detail/samsung-electro-mechanics/CL05B104KO5NNNC/3889087 | 100 nF ±10%, 16 V, X7R, 0402 | 0.09 | 1 | 2026-09-27 | Stock 103052 | Voir composants/catalogue.json et verification/REPORT.md | Voir composants/README.md | DigiKey France | 1276-1001-1-ND | https://www.digikey.fr/fr/products/detail/samsung-electro-mechanics/CL05B104KO5NNNC/3889087
CAN.kicad_sch | C42 | 100n | Samsung Electro-Mechanics | CL05B104KO5NNNC | 0402 (1005) | Capacitor_SMD:C_0402_1005Metric | ${KIPRJMOD}/composants/pdf/CL05B104KO5NNN.pdf | 1276-1001-1-ND | https://www.digikey.fr/fr/products/detail/samsung-electro-mechanics/CL05B104KO5NNNC/3889087 | 100 nF ±10%, 16 V, X7R, 0402 | 0.09 | 1 | 2026-09-27 | Stock 103052 | Voir composants/catalogue.json et verification/REPORT.md | Voir composants/README.md | DigiKey France | 1276-1001-1-ND | https://www.digikey.fr/fr/products/detail/samsung-electro-mechanics/CL05B104KO5NNNC/3889087
CAN.kicad_sch | C43 | 100n | Samsung Electro-Mechanics | CL05B104KO5NNNC | 0402 (1005) | Capacitor_SMD:C_0402_1005Metric | ${KIPRJMOD}/composants/pdf/CL05B104KO5NNN.pdf | 1276-1001-1-ND | https://www.digikey.fr/fr/products/detail/samsung-electro-mechanics/CL05B104KO5NNNC/3889087 | 100 nF ±10%, 16 V, X7R, 0402 | 0.09 | 1 | 2026-09-27 | Stock 103052 | Voir composants/catalogue.json et verification/REPORT.md | Voir composants/README.md | DigiKey France | 1276-1001-1-ND | https://www.digikey.fr/fr/products/detail/samsung-electro-mechanics/CL05B104KO5NNNC/3889087
SENSORS.kicad_sch | C44 | 4.7u | Samsung Electro-Mechanics | CL05A475MP5NRNC | 0402 (1005) | Capacitor_SMD:C_0402_1005Metric | ${KIPRJMOD}/composants/pdf/CL05A475MP5NRN.pdf | 1276-1482-1-ND | https://www.digikey.fr/en/products/detail/samsung-electro-mechanics/CL05A475MP5NRNC/3889568 | 4.7 µF ±20%, 10 V, X5R, 0402 | 0.09 | 1 | 2026-09-27 | Stock 0 | Voir composants/catalogue.json et verification/REPORT.md | Voir composants/README.md | DigiKey France | 1276-1482-1-ND | https://www.digikey.fr/en/products/detail/samsung-electro-mechanics/CL05A475MP5NRNC/3889568
SENSORS.kicad_sch | C45 | 4.7u | Samsung Electro-Mechanics | CL05A475MP5NRNC | 0402 (1005) | Capacitor_SMD:C_0402_1005Metric | ${KIPRJMOD}/composants/pdf/CL05A475MP5NRN.pdf | 1276-1482-1-ND | https://www.digikey.fr/en/products/detail/samsung-electro-mechanics/CL05A475MP5NRNC/3889568 | 4.7 µF ±20%, 10 V, X5R, 0402 | 0.09 | 1 | 2026-09-27 | Stock 0 | Voir composants/catalogue.json et verification/REPORT.md | Voir composants/README.md | DigiKey France | 1276-1482-1-ND | https://www.digikey.fr/en/products/detail/samsung-electro-mechanics/CL05A475MP5NRNC/3889568
SENSORS.kicad_sch | C46 | 4.7u | Samsung Electro-Mechanics | CL05A475MP5NRNC | 0402 (1005) | Capacitor_SMD:C_0402_1005Metric | ${KIPRJMOD}/composants/pdf/CL05A475MP5NRN.pdf | 1276-1482-1-ND | https://www.digikey.fr/en/products/detail/samsung-electro-mechanics/CL05A475MP5NRNC/3889568 | 4.7 µF ±20%, 10 V, X5R, 0402 | 0.09 | 1 | 2026-09-27 | Stock 0 | Voir composants/catalogue.json et verification/REPORT.md | Voir composants/README.md | DigiKey France | 1276-1482-1-ND | https://www.digikey.fr/en/products/detail/samsung-electro-mechanics/CL05A475MP5NRNC/3889568
SENSORS.kicad_sch | C47 | 100n X7R | Samsung Electro-Mechanics | CL05B104KO5NNNC | 0402 (1005) | Capacitor_SMD:C_0402_1005Metric | ${KIPRJMOD}/composants/pdf/CL05B104KO5NNN.pdf | 1276-1001-1-ND | https://www.digikey.fr/fr/products/detail/samsung-electro-mechanics/CL05B104KO5NNNC/3889087 | 100 nF ±10%, 16 V, X7R, 0402 | 0.09 | 1 | 2026-09-27 | Stock 103052 | Voir composants/catalogue.json et verification/REPORT.md | Voir composants/README.md | DigiKey France | 1276-1001-1-ND | https://www.digikey.fr/fr/products/detail/samsung-electro-mechanics/CL05B104KO5NNNC/3889087
SENSORS.kicad_sch | C48 | 100n X7R | Samsung Electro-Mechanics | CL05B104KO5NNNC | 0402 (1005) | Capacitor_SMD:C_0402_1005Metric | ${KIPRJMOD}/composants/pdf/CL05B104KO5NNN.pdf | 1276-1001-1-ND | https://www.digikey.fr/fr/products/detail/samsung-electro-mechanics/CL05B104KO5NNNC/3889087 | 100 nF ±10%, 16 V, X7R, 0402 | 0.09 | 1 | 2026-09-27 | Stock 103052 | Voir composants/catalogue.json et verification/REPORT.md | Voir composants/README.md | DigiKey France | 1276-1001-1-ND | https://www.digikey.fr/fr/products/detail/samsung-electro-mechanics/CL05B104KO5NNNC/3889087
SENSORS.kicad_sch | C49 | 100n X7R | Samsung Electro-Mechanics | CL05B104KO5NNNC | 0402 (1005) | Capacitor_SMD:C_0402_1005Metric | ${KIPRJMOD}/composants/pdf/CL05B104KO5NNN.pdf | 1276-1001-1-ND | https://www.digikey.fr/fr/products/detail/samsung-electro-mechanics/CL05B104KO5NNNC/3889087 | 100 nF ±10%, 16 V, X7R, 0402 | 0.09 | 1 | 2026-09-27 | Stock 103052 | Voir composants/catalogue.json et verification/REPORT.md | Voir composants/README.md | DigiKey France | 1276-1001-1-ND | https://www.digikey.fr/fr/products/detail/samsung-electro-mechanics/CL05B104KO5NNNC/3889087
SENSORS.kicad_sch | C50 | 100n X7R | Samsung Electro-Mechanics | CL05B104KO5NNNC | 0402 (1005) | Capacitor_SMD:C_0402_1005Metric | ${KIPRJMOD}/composants/pdf/CL05B104KO5NNN.pdf | 1276-1001-1-ND | https://www.digikey.fr/fr/products/detail/samsung-electro-mechanics/CL05B104KO5NNNC/3889087 | 100 nF ±10%, 16 V, X7R, 0402 | 0.09 | 1 | 2026-09-27 | Stock 103052 | Voir composants/catalogue.json et verification/REPORT.md | Voir composants/README.md | DigiKey France | 1276-1001-1-ND | https://www.digikey.fr/fr/products/detail/samsung-electro-mechanics/CL05B104KO5NNNC/3889087
SENSORS.kicad_sch | C51 | 100n X7R | Samsung Electro-Mechanics | CL05B104KO5NNNC | 0402 (1005) | Capacitor_SMD:C_0402_1005Metric | ${KIPRJMOD}/composants/pdf/CL05B104KO5NNN.pdf | 1276-1001-1-ND | https://www.digikey.fr/fr/products/detail/samsung-electro-mechanics/CL05B104KO5NNNC/3889087 | 100 nF ±10%, 16 V, X7R, 0402 | 0.09 | 1 | 2026-09-27 | Stock 103052 | Voir composants/catalogue.json et verification/REPORT.md | Voir composants/README.md | DigiKey France | 1276-1001-1-ND | https://www.digikey.fr/fr/products/detail/samsung-electro-mechanics/CL05B104KO5NNNC/3889087
SENSORS.kicad_sch | C52 | 100n X7R | Samsung Electro-Mechanics | CL05B104KO5NNNC | 0402 (1005) | Capacitor_SMD:C_0402_1005Metric | ${KIPRJMOD}/composants/pdf/CL05B104KO5NNN.pdf | 1276-1001-1-ND | https://www.digikey.fr/fr/products/detail/samsung-electro-mechanics/CL05B104KO5NNNC/3889087 | 100 nF ±10%, 16 V, X7R, 0402 | 0.09 | 1 | 2026-09-27 | Stock 103052 | Voir composants/catalogue.json et verification/REPORT.md | Voir composants/README.md | DigiKey France | 1276-1001-1-ND | https://www.digikey.fr/fr/products/detail/samsung-electro-mechanics/CL05B104KO5NNNC/3889087
SENSORS.kicad_sch | C53 | 100n | Samsung Electro-Mechanics | CL05B104KO5NNNC | 0402 (1005) | Capacitor_SMD:C_0402_1005Metric | ${KIPRJMOD}/composants/pdf/CL05B104KO5NNN.pdf | 1276-1001-1-ND | https://www.digikey.fr/fr/products/detail/samsung-electro-mechanics/CL05B104KO5NNNC/3889087 | 100 nF ±10%, 16 V, X7R, 0402 | 0.09 | 1 | 2026-09-27 | Stock 103052 | Voir composants/catalogue.json et verification/REPORT.md | Voir composants/README.md | DigiKey France | 1276-1001-1-ND | https://www.digikey.fr/fr/products/detail/samsung-electro-mechanics/CL05B104KO5NNNC/3889087
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

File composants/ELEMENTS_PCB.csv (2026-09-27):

Reference | Value | Symbol | Footprint | 3D / achat
H1 | MountingHole_Pad | FC01_Project:H743_Ardupilot__MountingHole_Pad | MountingHole:MountingHole_3.2mm_M3_ISO7380_Pad | Non applicable: pastille, point test, cavalier cuivre ou trou du PCB; pas de composant achete.
H2 | MountingHole_Pad | FC01_Project:H743_Ardupilot__MountingHole_Pad | MountingHole:MountingHole_3.2mm_M3_ISO7380_Pad | Non applicable: pastille, point test, cavalier cuivre ou trou du PCB; pas de composant achete.
H3 | MountingHole_Pad | FC01_Project:H743_Ardupilot__MountingHole_Pad | MountingHole:MountingHole_3.2mm_M3_ISO7380_Pad | Non applicable: pastille, point test, cavalier cuivre ou trou du PCB; pas de composant achete.
H4 | MountingHole_Pad | FC01_Project:H743_Ardupilot__MountingHole_Pad | MountingHole:MountingHole_3.2mm_M3_ISO7380_Pad | Non applicable: pastille, point test, cavalier cuivre ou trou du PCB; pas de composant achete.
J1 | Analog | FC01_Project:ANALOG_SENS__Conn_01x04 | H743_Custom:SolderPadArray_1x04_P2.54mm_1x1mm | Non applicable: pastille, point test, cavalier cuivre ou trou du PCB; pas de composant achete.
J2 | Uart1 | FC01_Project:UART_I2C__Conn_01x04 | H743_Custom:SolderPadArray_1x04_P2.54mm_1x1mm | Non applicable: pastille, point test, cavalier cuivre ou trou du PCB; pas de composant achete.
J3 | Uart4 | FC01_Project:UART_I2C__Conn_01x04 | H743_Custom:SolderPadArray_1x04_P2.54mm_1x1mm | Non applicable: pastille, point test, cavalier cuivre ou trou du PCB; pas de composant achete.
J4 | Uart7 | FC01_Project:UART_I2C__Conn_01x06 | H743_Custom:SolderPadArray_1x06_P2.54mm_1x1mm | Non applicable: pastille, point test, cavalier cuivre ou trou du PCB; pas de composant achete.
J5 | Uart( | FC01_Project:UART_I2C__Conn_01x04 | H743_Custom:SolderPadArray_1x04_P2.54mm_1x1mm | Non applicable: pastille, point test, cavalier cuivre ou trou du PCB; pas de composant achete.
J6 | Uart6 | FC01_Project:UART_I2C__Conn_01x04 | H743_Custom:SolderPadArray_1x04_P2.54mm_1x1mm | Non applicable: pastille, point test, cavalier cuivre ou trou du PCB; pas de composant achete.
J7 | Uart3 | FC01_Project:UART_I2C__Conn_01x04 | H743_Custom:SolderPadArray_1x04_P2.54mm_1x1mm | Non applicable: pastille, point test, cavalier cuivre ou trou du PCB; pas de composant achete.
J8 | I2C1 | FC01_Project:SENSORS__Conn_01x04 | H743_Custom:SolderPadArray_1x04_P2.54mm_1x1mm | Non applicable: pastille, point test, cavalier cuivre ou trou du PCB; pas de composant achete.
J9 | I2C_2 | FC01_Project:SENSORS__Conn_01x04 | H743_Custom:SolderPadArray_1x04_P2.54mm_1x1mm | Non applicable: pastille, point test, cavalier cuivre ou trou du PCB; pas de composant achete.
J10 | Led ext | FC01_Project:BUZZER__Conn_01x03 | H743_Custom:SolderPadArray_1x03_P2.54mm_1x1mm | Non applicable: pastille, point test, cavalier cuivre ou trou du PCB; pas de composant achete.
J11 | Buzzer | FC01_Project:BUZZER__Conn_01x03 | H743_Custom:SolderPadArray_1x03_P2.54mm_1x1mm | Non applicable: pastille, point test, cavalier cuivre ou trou du PCB; pas de composant achete.
J13 | Can1_2 | FC01_Project:CAN__Conn_01x04 | H743_Custom:SolderPadArray_1x04_P2.54mm_1x1mm | Non applicable: pastille, point test, cavalier cuivre ou trou du PCB; pas de composant achete.
J14 | Can1_1 | FC01_Project:CAN__Conn_01x04 | H743_Custom:SolderPadArray_1x04_P2.54mm_1x1mm | Non applicable: pastille, point test, cavalier cuivre ou trou du PCB; pas de composant achete.
JP1 | SolderJumper_2_Open | FC01_Project:MCU__SolderJumper_2_Open | Jumper:SolderJumper-2_P1.3mm_Open_RoundedPad1.0x1.5mm | Non applicable: pastille, point test, cavalier cuivre ou trou du PCB; pas de composant achete.
TP1 | SWDIO | FC01_Project:MCU__TestPoint | TestPoint:TestPoint_Pad_1.0x1.0mm | Non applicable: pastille, point test, cavalier cuivre ou trou du PCB; pas de composant achete.
TP2 | SWCLK | FC01_Project:MCU__TestPoint | TestPoint:TestPoint_Pad_1.0x1.0mm | Non applicable: pastille, point test, cavalier cuivre ou trou du PCB; pas de composant achete.
TP3 | +3V3_MCU | FC01_Project:MCU__TestPoint | TestPoint:TestPoint_Pad_1.0x1.0mm | Non applicable: pastille, point test, cavalier cuivre ou trou du PCB; pas de composant achete.
TP4 | GND | FC01_Project:MCU__TestPoint | TestPoint:TestPoint_Pad_1.0x1.0mm | Non applicable: pastille, point test, cavalier cuivre ou trou du PCB; pas de composant achete.

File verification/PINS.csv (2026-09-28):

Reference | Pin | Symbol_pin_name | PCB_net | No_connect | Library_pad_geometry_mm
C1 | 1 |  | +3V3_MCU | False | [{"at": ["-0.48", "0", "0"], "size": ["0.56", "0.62"], "shape": "roundrect", "mask_margin": ""}]
C1 | 2 |  | GND | False | [{"at": ["0.48", "0", "0"], "size": ["0.56", "0.62"], "shape": "roundrect", "mask_margin": ""}]
C2 | 1 |  | +3V3_MCU | False | [{"at": ["-0.48", "0", "0"], "size": ["0.56", "0.62"], "shape": "roundrect", "mask_margin": ""}]
C2 | 2 |  | GND | False | [{"at": ["0.48", "0", "0"], "size": ["0.56", "0.62"], "shape": "roundrect", "mask_margin": ""}]
C3 | 1 |  | /MCU/VDDA | False | [{"at": ["-0.48", "0", "0"], "size": ["0.56", "0.62"], "shape": "roundrect", "mask_margin": ""}]
C3 | 2 |  | GND | False | [{"at": ["0.48", "0", "0"], "size": ["0.56", "0.62"], "shape": "roundrect", "mask_margin": ""}]
C4 | 1 |  | +3V3_MCU | False | [{"at": ["-0.48", "0", "0"], "size": ["0.56", "0.62"], "shape": "roundrect", "mask_margin": ""}]
C4 | 2 |  | GND | False | [{"at": ["0.48", "0", "0"], "size": ["0.56", "0.62"], "shape": "roundrect", "mask_margin": ""}]
C5 | 1 |  | +3V3_MCU | False | [{"at": ["-0.48", "0", "0"], "size": ["0.56", "0.62"], "shape": "roundrect", "mask_margin": ""}]
C5 | 2 |  | GND | False | [{"at": ["0.48", "0", "0"], "size": ["0.56", "0.62"], "shape": "roundrect", "mask_margin": ""}]
C6 | 1 |  | +3V3_MCU | False | [{"at": ["-0.48", "0", "0"], "size": ["0.56", "0.62"], "shape": "roundrect", "mask_margin": ""}]
C6 | 2 |  | GND | False | [{"at": ["0.48", "0", "0"], "size": ["0.56", "0.62"], "shape": "roundrect", "mask_margin": ""}]
C7 | 1 |  | VCAP | False | [{"at": ["-0.48", "0", "0"], "size": ["0.56", "0.62"], "shape": "roundrect", "mask_margin": ""}]
C7 | 2 |  | GND | False | [{"at": ["0.48", "0", "0"], "size": ["0.56", "0.62"], "shape": "roundrect", "mask_margin": ""}]
C8 | 1 |  | +3V3_MCU | False | [{"at": ["-0.48", "0", "0"], "size": ["0.56", "0.62"], "shape": "roundrect", "mask_margin": ""}]
C8 | 2 |  | GND | False | [{"at": ["0.48", "0", "0"], "size": ["0.56", "0.62"], "shape": "roundrect", "mask_margin": ""}]
C9 | 1 |  | /MCU/NRST | False | [{"at": ["-0.48", "0", "0"], "size": ["0.56", "0.62"], "shape": "roundrect", "mask_margin": ""}]
C9 | 2 |  | GND | False | [{"at": ["0.48", "0", "0"], "size": ["0.56", "0.62"], "shape": "roundrect", "mask_margin": ""}]
C10 | 1 |  | VCAP | False | [{"at": ["-0.48", "0", "0"], "size": ["0.56", "0.62"], "shape": "roundrect", "mask_margin": ""}]
C10 | 2 |  | GND | False | [{"at": ["0.48", "0", "0"], "size": ["0.56", "0.62"], "shape": "roundrect", "mask_margin": ""}]
C11 | 1 |  | +3V3_MCU | False | [{"at": ["-0.48", "0", "0"], "size": ["0.56", "0.62"], "shape": "roundrect", "mask_margin": ""}]
C11 | 2 |  | GND | False | [{"at": ["0.48", "0", "0"], "size": ["0.56", "0.62"], "shape": "roundrect", "mask_margin": ""}]
C12 | 1 |  | +3V3_MCU | False | [{"at": ["-0.48", "0", "0"], "size": ["0.56", "0.62"], "shape": "roundrect", "mask_margin": ""}]
C12 | 2 |  | GND | False | [{"at": ["0.48", "0", "0"], "size": ["0.56", "0.62"], "shape": "roundrect", "mask_margin": ""}]
C14 | 1 |  | /MCU/VDDA | False | [{"at": ["-0.48", "0", "0"], "size": ["0.56", "0.62"], "shape": "roundrect", "mask_margin": ""}]
C14 | 2 |  | GND | False | [{"at": ["0.48", "0", "0"], "size": ["0.56", "0.62"], "shape": "roundrect", "mask_margin": ""}]
C15 | 1 |  | /MCU/VDDA | False | [{"at": ["-0.48", "0", "0"], "size": ["0.56", "0.62"], "shape": "roundrect", "mask_margin": ""}]
C15 | 2 |  | GND | False | [{"at": ["0.48", "0", "0"], "size": ["0.56", "0.62"], "shape": "roundrect", "mask_margin": ""}]
C16 | 1 |  | VBAT | False | [{"at": ["-0.95", "0", "0.0"], "size": ["1", "1.45"], "shape": "roundrect", "mask_margin": ""}]
C16 | 2 |  | GND | False | [{"at": ["0.95", "0", "0.0"], "size": ["1", "1.45"], "shape": "roundrect", "mask_margin": ""}]
C17 | 1 |  | VBAT | False | [{"at": ["-0.48", "0", "0"], "size": ["0.56", "0.62"], "shape": "roundrect", "mask_margin": ""}]
C17 | 2 |  | GND | False | [{"at": ["0.48", "0", "0"], "size": ["0.56", "0.62"], "shape": "roundrect", "mask_margin": ""}]
C18 | 1 |  | VBAT | False | [{"at": ["-0.95", "0", "0.0"], "size": ["1", "1.45"], "shape": "roundrect", "mask_margin": ""}]
C18 | 2 |  | GND | False | [{"at": ["0.95", "0", "0.0"], "size": ["1", "1.45"], "shape": "roundrect", "mask_margin": ""}]
C19 | 1 |  | VBAT | False | [{"at": ["-0.48", "0", "0"], "size": ["0.56", "0.62"], "shape": "roundrect", "mask_margin": ""}]
C19 | 2 |  | GND | False | [{"at": ["0.48", "0", "0"], "size": ["0.56", "0.62"], "shape": "roundrect", "mask_margin": ""}]
C20 | 1 |  | Net-(U3-VCC) | False | [{"at": ["-0.775", "0", "0"], "size": ["0.9", "0.95"], "shape": "roundrect", "mask_margin": ""}]
C20 | 2 |  | GND | False | [{"at": ["0.775", "0", "0"], "size": ["0.9", "0.95"], "shape": "roundrect", "mask_margin": ""}]
C21 | 1 |  | Net-(U3-BOOT) | False | [{"at": ["-0.48", "0", "0"], "size": ["0.56", "0.62"], "shape": "roundrect", "mask_margin": ""}]
C21 | 2 |  | /POWER/SW_5V | False | [{"at": ["0.48", "0", "0"], "size": ["0.56", "0.62"], "shape": "roundrect", "mask_margin": ""}]
C22 | 1 |  | Net-(U4-BOOT) | False | [{"at": ["-0.48", "0", "0"], "size": ["0.56", "0.62"], "shape": "roundrect", "mask_margin": ""}]
C22 | 2 |  | /POWER/SW_9V | False | [{"at": ["0.48", "0", "0"], "size": ["0.56", "0.62"], "shape": "roundrect", "mask_margin": ""}]
C23 | 1 |  | +5V | False | [{"at": ["-0.95", "0", "0.0"], "size": ["1", "1.45"], "shape": "roundrect", "mask_margin": ""}]
C23 | 2 |  | GND | False | [{"at": ["0.95", "0", "0.0"], "size": ["1", "1.45"], "shape": "roundrect", "mask_margin": ""}]
C24 | 1 |  | +5V | False | [{"at": ["-0.95", "0", "0.0"], "size": ["1", "1.45"], "shape": "roundrect", "mask_margin": ""}]
C24 | 2 |  | GND | False | [{"at": ["0.95", "0", "0.0"], "size": ["1", "1.45"], "shape": "roundrect", "mask_margin": ""}]
C25 | 1 |  | +5V | False | [{"at": ["-0.48", "0", "0"], "size": ["0.56", "0.62"], "shape": "roundrect", "mask_margin": ""}]
C25 | 2 |  | GND | False | [{"at": ["0.48", "0", "0"], "size": ["0.56", "0.62"], "shape": "roundrect", "mask_margin": ""}]
C26 | 1 |  | +9V | False | [{"at": ["-0.95", "0", "0.0"], "size": ["1", "1.45"], "shape": "roundrect", "mask_margin": ""}]
C26 | 2 |  | GND | False | [{"at": ["0.95", "0", "0.0"], "size": ["1", "1.45"], "shape": "roundrect", "mask_margin": ""}]
C27 | 1 |  | +9V | False | [{"at": ["-0.95", "0", "0.0"], "size": ["1", "1.45"], "shape": "roundrect", "mask_margin": ""}]
C27 | 2 |  | GND | False | [{"at": ["0.95", "0", "0.0"], "size": ["1", "1.45"], "shape": "roundrect", "mask_margin": ""}]
C28 | 1 |  | +9V | False | [{"at": ["-0.48", "0", "0"], "size": ["0.56", "0.62"], "shape": "roundrect", "mask_margin": ""}]
C28 | 2 |  | GND | False | [{"at": ["0.48", "0", "0"], "size": ["0.56", "0.62"], "shape": "roundrect", "mask_margin": ""}]
C29 | 1 |  | +5V_SYS | False | [{"at": ["-0.775", "0", "0"], "size": ["0.9", "0.95"], "shape": "roundrect", "mask_margin": ""}]
C29 | 2 |  | GND | False | [{"at": ["0.775", "0", "0"], "size": ["0.9", "0.95"], "shape": "roundrect", "mask_margin": ""}]
C30 | 1 |  | +5V_SYS | False | [{"at": ["-0.775", "0", "0"], "size": ["0.9", "0.95"], "shape": "roundrect", "mask_margin": ""}]
C30 | 2 |  | GND | False | [{"at": ["0.775", "0", "0"], "size": ["0.9", "0.95"], "shape": "roundrect", "mask_margin": ""}]
C31 | 1 |  | +3V3_MCU | False | [{"at": ["-0.775", "0", "0"], "size": ["0.9", "0.95"], "shape": "roundrect", "mask_margin": ""}]
C31 | 2 |  | GND | False | [{"at": ["0.775", "0", "0"], "size": ["0.9", "0.95"], "shape": "roundrect", "mask_margin": ""}]
C32 | 1 |  | +3V3_SENS | False | [{"at": ["-0.775", "0", "0"], "size": ["0.9", "0.95"], "shape": "roundrect", "mask_margin": ""}]
C32 | 2 |  | GND | False | [{"at": ["0.775", "0", "0"], "size": ["0.9", "0.95"], "shape": "roundrect", "mask_margin": ""}]
C33 | 1 |  | /ANALOG_SENS/ADC_VBAT1 | False | [{"at": ["-0.48", "0", "0"], "size": ["0.56", "0.62"], "shape": "roundrect", "mask_margin": ""}]
C33 | 2 |  | GND | False | [{"at": ["0.48", "0", "0"], "size": ["0.56", "0.62"], "shape": "roundrect", "mask_margin": ""}]
C34 | 1 |  | /ANALOG_SENS/ADC_AIRSPEED | False | [{"at": ["-0.48", "0", "0"], "size": ["0.56", "0.62"], "shape": "roundrect", "mask_margin": ""}]
C34 | 2 |  | GND | False | [{"at": ["0.48", "0", "0"], "size": ["0.56", "0.62"], "shape": "roundrect", "mask_margin": ""}]
C35 | 1 |  | /ANALOG_SENS/ADC_VBAT2 | False | [{"at": ["-0.48", "0", "0"], "size": ["0.56", "0.62"], "shape": "roundrect", "mask_margin": ""}]
C35 | 2 |  | GND | False | [{"at": ["0.48", "0", "0"], "size": ["0.56", "0.62"], "shape": "roundrect", "mask_margin": ""}]
C36 | 1 |  | +5V | False | [{"at": ["-0.48", "0", "0"], "size": ["0.56", "0.62"], "shape": "roundrect", "mask_margin": ""}]
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

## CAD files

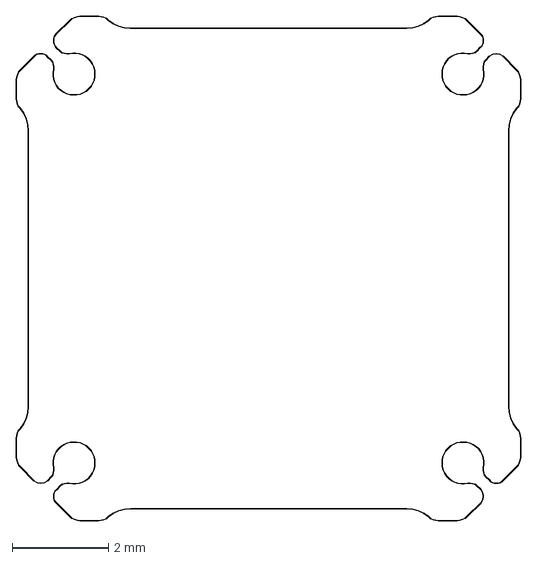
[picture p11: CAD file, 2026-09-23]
pcb_1.dxf
10.5 x 10.5 mm

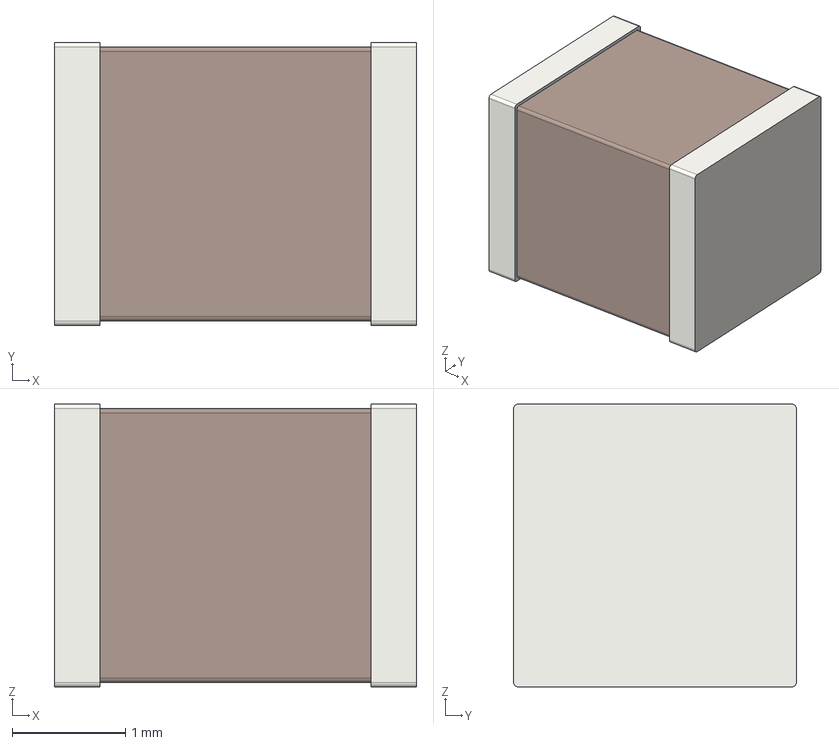
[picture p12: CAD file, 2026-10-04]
composants/3d/C_1210_3225Metric.step
3.20 x 2.50 x 2.50 mm

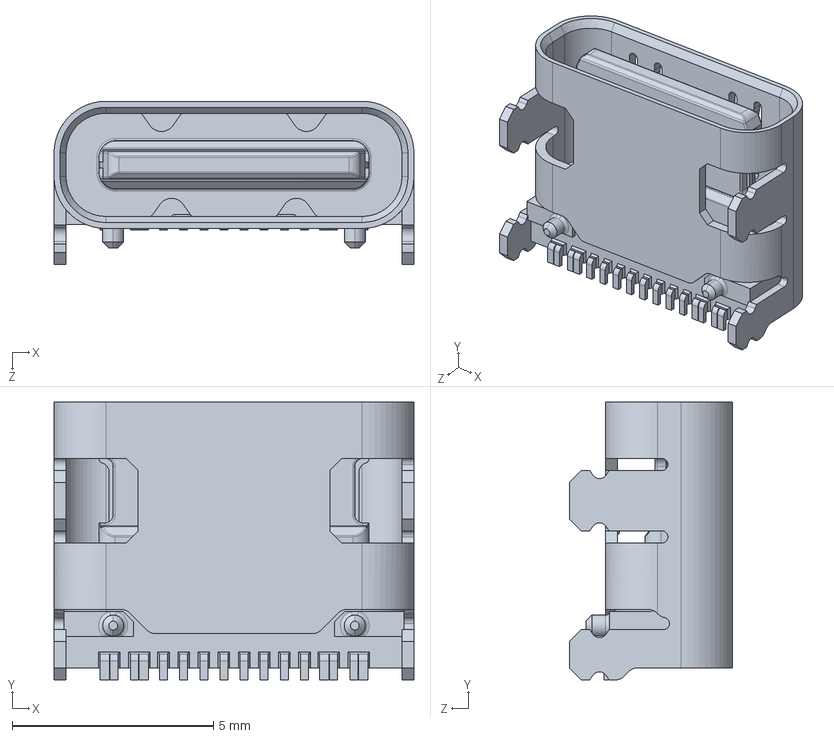
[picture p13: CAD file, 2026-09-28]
composants/3d/DX07S016JA1R1500.step
8.94 x 6.90 x 4.06 mm

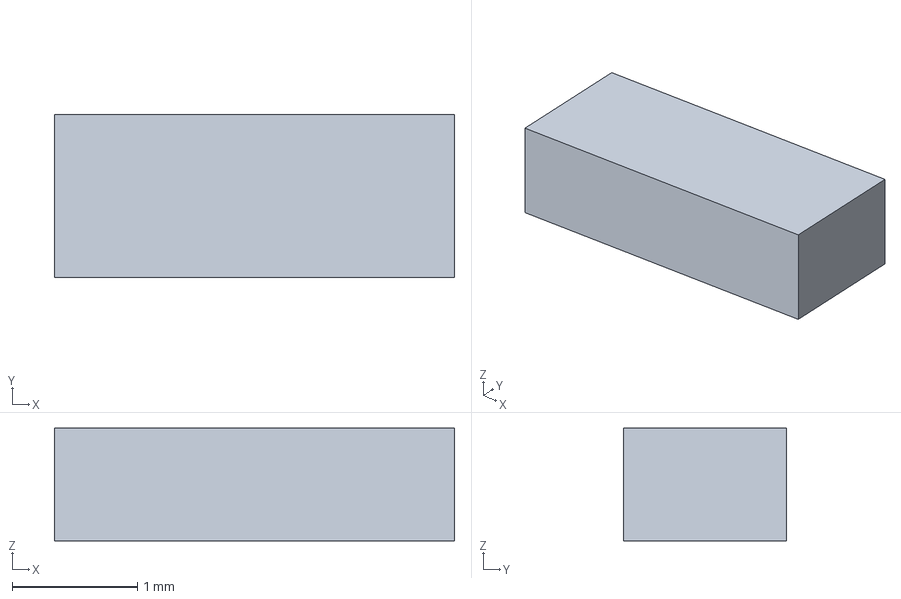
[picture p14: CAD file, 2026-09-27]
composants/3d/Murata_CSTNE_envelope.step
3.20 x 1.30 x 0.9 mm

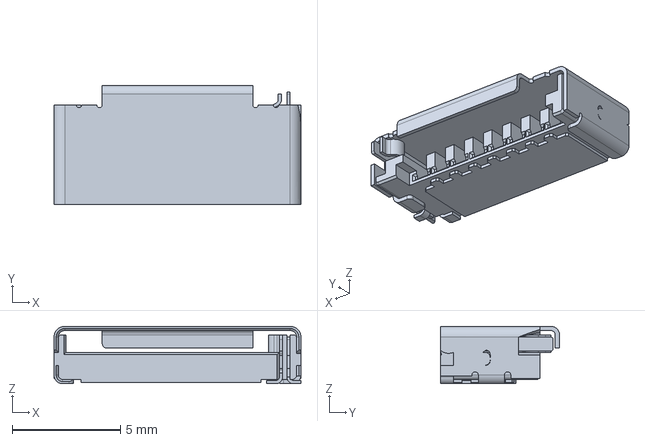
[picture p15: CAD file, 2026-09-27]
composants/3d/Amphenol_10067099-200LF_aligned.step
11.4 x 5.50 x 2.65 mm

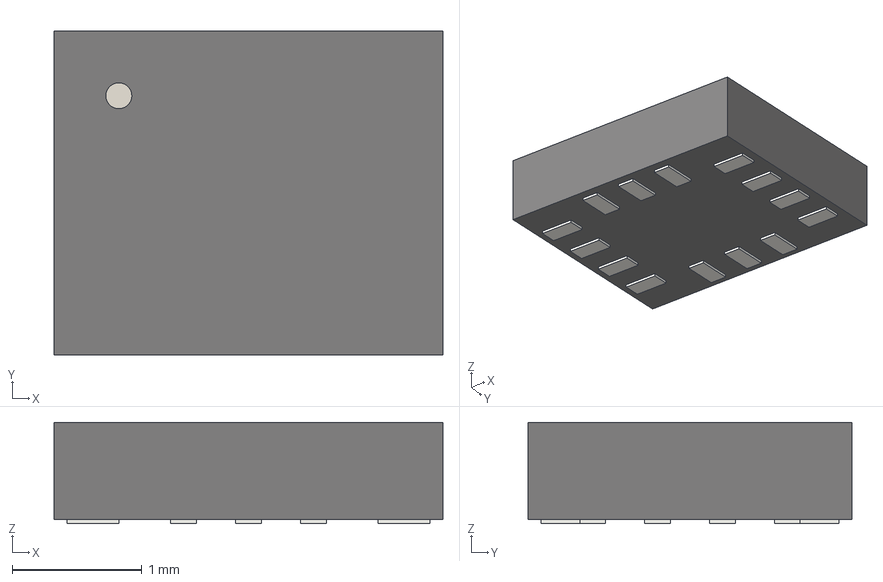
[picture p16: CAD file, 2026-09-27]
composants/3d/LGA-14_3x2.5mm_P0.5mm_LayoutBorder3x4y.step
3.00 x 2.50 x 0.78 mm

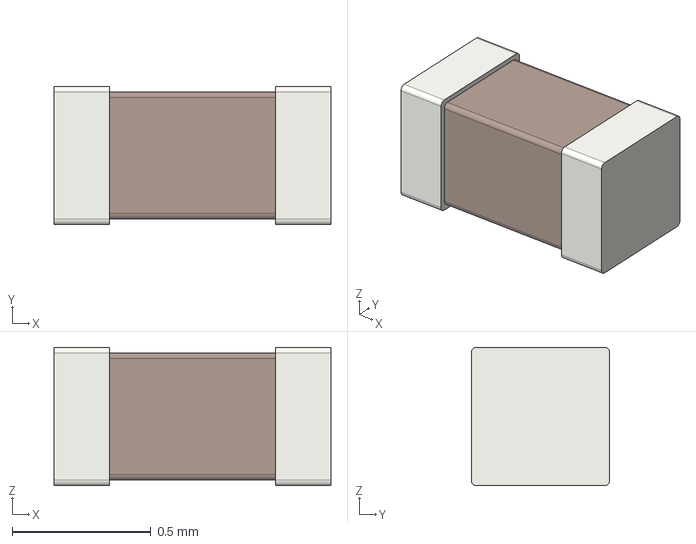
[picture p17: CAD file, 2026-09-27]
composants/3d/C_0402_1005Metric.step
1.00 x 0.5 x 0.5 mm

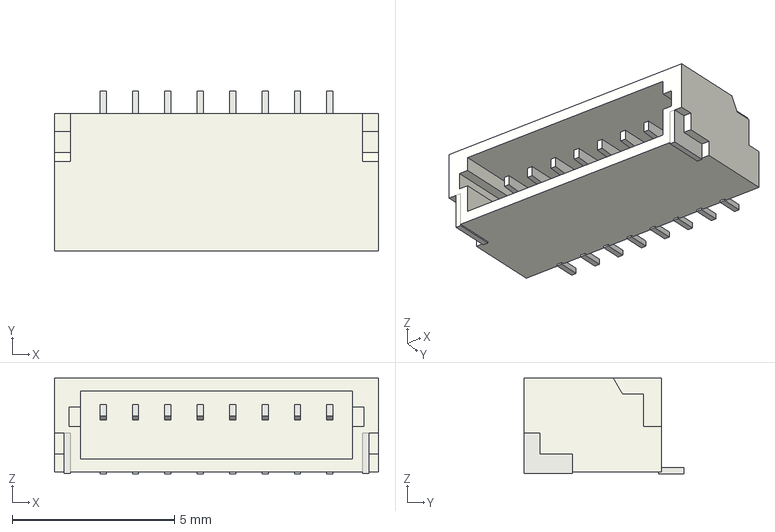
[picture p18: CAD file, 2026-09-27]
composants/3d/JST_SH_SM08B-SRSS-TB_1x08-1MP_P1.00mm_Horizontal.step
10.0 x 4.95 x 2.96 mm

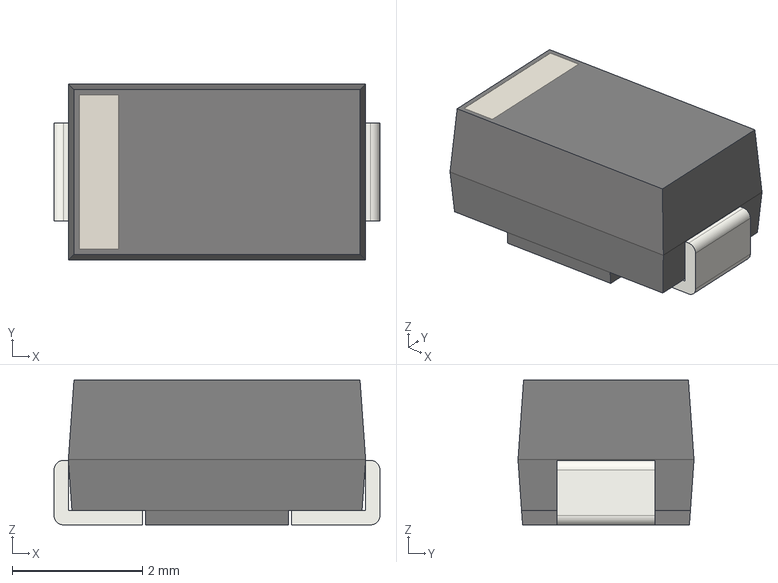
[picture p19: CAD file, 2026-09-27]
composants/3d/D_SMA.step
5.00 x 2.70 x 2.22 mm

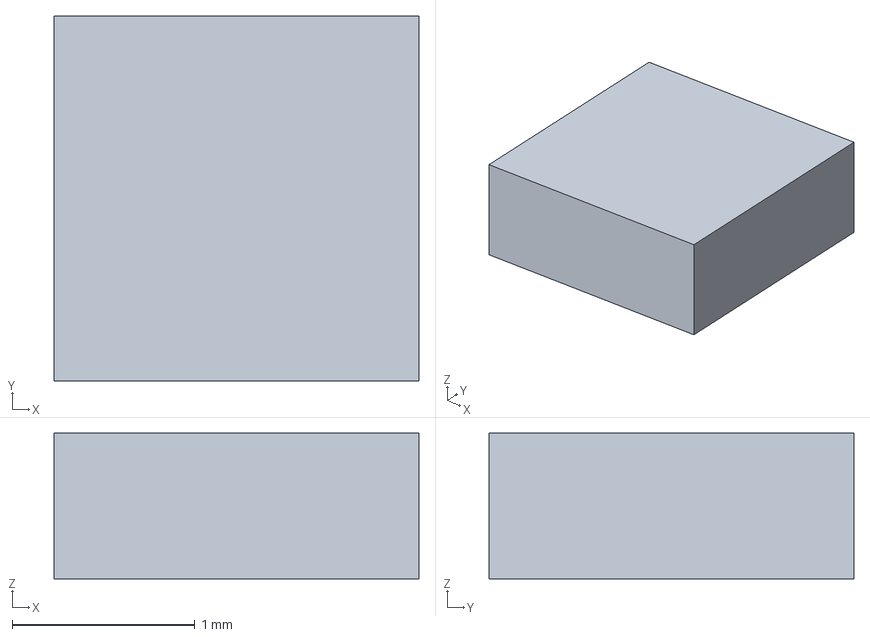
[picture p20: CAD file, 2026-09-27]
composants/3d/BMP581_envelope.step
2.00 x 2.00 x 0.8 mm

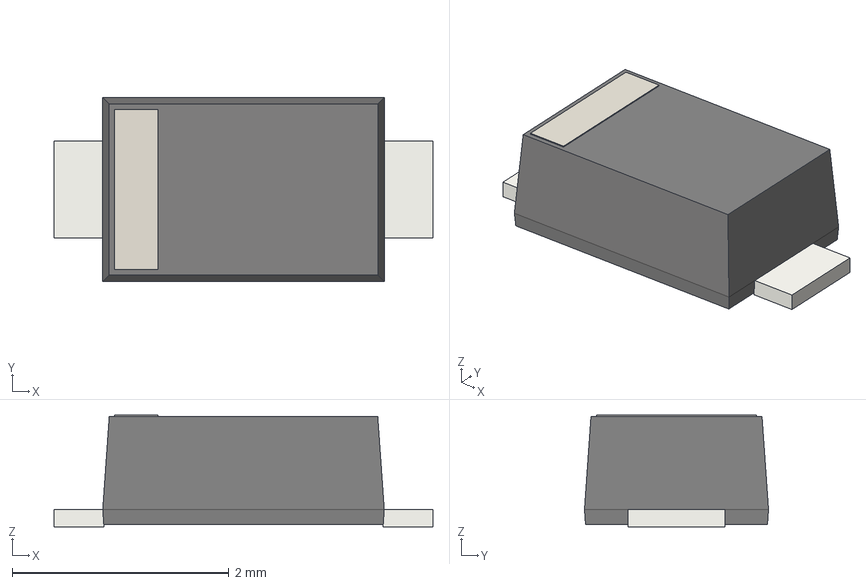
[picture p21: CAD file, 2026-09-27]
composants/3d/Nexperia_CFP3_SOD-123W.step
3.50 x 1.70 x 1.03 mm
6081697a-9268-11ed-8af4-a0cec80452fd_part
60816e3e-9268-11ed-8af4-a0cec80452fd_part
6081710e-9268-11ed-8af4-a0cec80452fd_part
6081737a-9268-11ed-8af4-a0cec80452fd_part

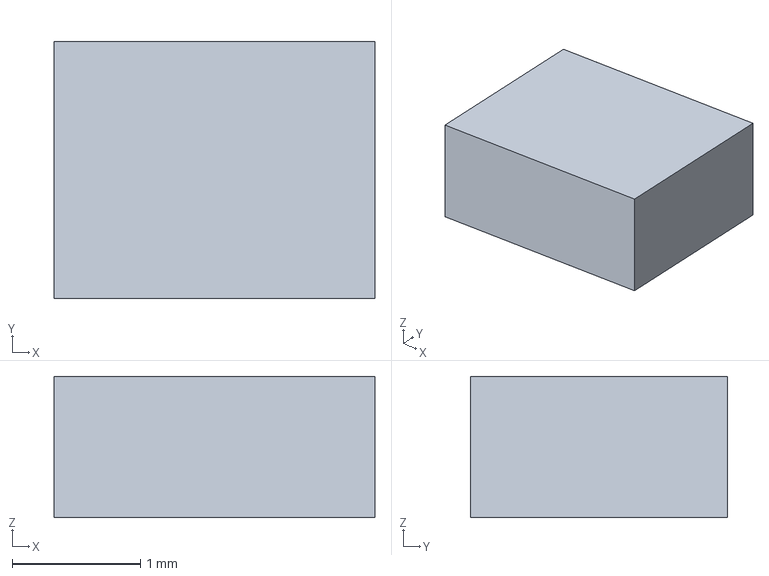
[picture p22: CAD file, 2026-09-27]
composants/3d/DPS368_envelope.step
2.50 x 2.00 x 1.10 mm

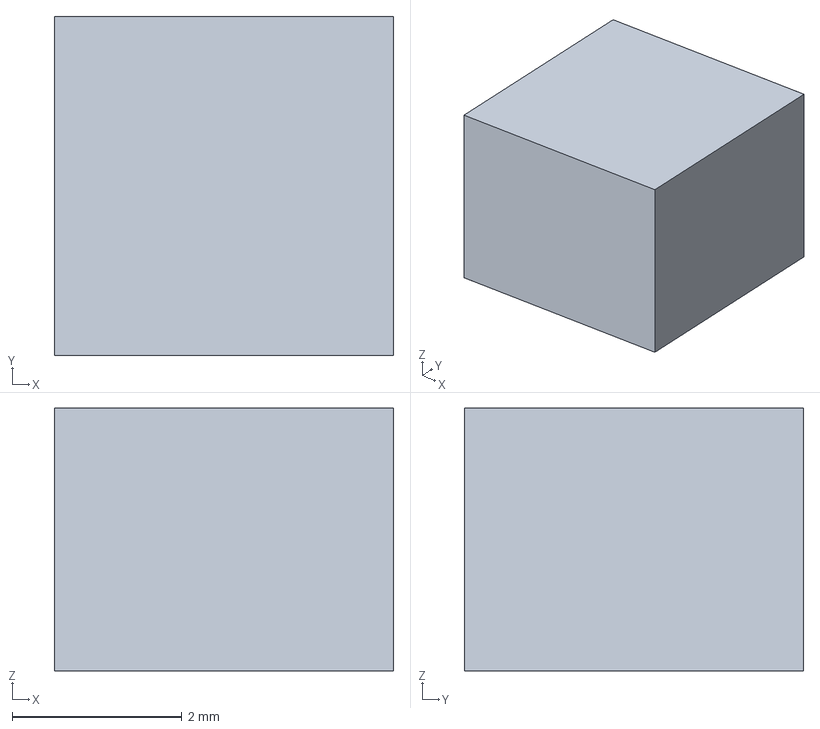
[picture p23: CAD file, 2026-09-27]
composants/3d/Coilcraft_XGL4030_envelope.step
4.00 x 4.00 x 3.10 mm

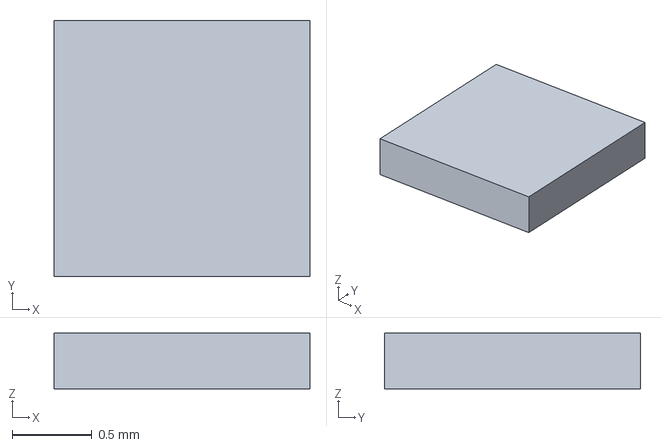
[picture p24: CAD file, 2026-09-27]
composants/3d/Everlight_19-337_envelope.step
1.60 x 1.60 x 0.35 mm

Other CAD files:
composants/3d/Amphenol_10067099-200LF_supplier.step
composants/3d/DFN-8-1EP_3x3mm_P0.65mm_EP1.5x2.25mm.step
composants/3d/Bosch_LGA-16_4.5x3mm_P0.5mm_LayoutBorder7x1y_ClockwisePinNumbering.step
composants/3d/SOT-666.step
composants/3d/C_0603_1608Metric.step
composants/3d/C_0805_2012Metric.step
composants/3d/D_SOD-123.step
composants/3d/JST_GH_SM04B-GHS-TB_1x04-1MP_P1.25mm_Horizontal.step
composants/3d/LMR43620_RPE0009B_envelope.step
composants/3d/LMR604305SRAKRQ1_RAK0009A.step
composants/3d/LMR60430_RAK0009A_envelope.step
composants/3d/LQFP-100_14x14mm_P0.5mm.step
composants/3d/L_0402_1005Metric.step
composants/3d/R_0402_1005Metric.step
composants/3d/SOT-23.step
composants/3d/TJA1051_HVSON8_envelope.step

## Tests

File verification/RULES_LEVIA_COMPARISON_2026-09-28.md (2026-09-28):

# FC_01 — règles inspirées de LEVIA-H7 (28/09/2026)

Référence examinée : `piecol/LEVIA-H7`, branche `main`, projet `LEVIA_H7.kicad_pro` et `LEVIA_H7.kicad_dru`. Les minima et tailles proposés de LEVIA sont copiés dans `H743_Ardupilot.kicad_pro`; les affectations sont adaptées aux noms des nets FC_01.

| Paramètre | Ancien FC_01 | Nouveau FC_01 / LEVIA |
|---|---:|---:|
| Minimum cuivre/cuivre | 0 mm au niveau carte; 0,20 mm classe Default | 0,127 mm; Default 0,127 mm |
| Minimum cuivre/bord | 0,50 mm | 0,20 mm |
| Minimum largeur de piste | 0,20 mm | 0,127 mm |
| Via minimum / couronne minimum | 0,50 / 0,10 mm | 0,40 / 0,075 mm |
| Trous/pads traversants, écart trou/trou | 0,30 / 0,25 mm | 0,25 / 0,20 mm |
| Dégagement cuivre/trou | 0,25 mm | 0,20 mm |
| Zone par défaut, dégagement / largeur minimale | 0,50 / 0,25 mm | 0,152 / 0,20 mm |
| Zone par défaut, thermique gap / pont | 0,50 / 0,50 mm | 0,20 / 0,45 mm |

Les tailles prédéfinies de piste/via et les valeurs de la classe Default proviennent également du projet LEVIA. Les classes fonctionnelles FC_01 sont conservées et effectivement affectées par motifs : USB, I²C, SPI, SDIO, moteurs, CAN, rails d'alimentation, VCAP et HSE. Les classes `POWER`, `SENSITIVE` et `CAN` ont un dégagement de 0,127 mm afin que leurs pads de circuits fins ne soient pas contredits par l'ancien 0,25 mm; leurs largeurs de routage restent spécifiques. `USB_90R` prend la largeur 0,2037 mm, l'écart 0,2451 mm et le dégagement 0,148 mm de la classe USB LEVIA.

## Exceptions à la copie littérale

- **Pas de copie de `LEVIA_H7.kicad_dru`** : il diminue à 0,05 mm le dégagement des pads au bord et l'autorise à −1 mm pour H1–H4. Ces exceptions ne conviennent pas automatiquement aux trous métallisés Ø5,7 mm et au contour FC_01; leurs erreurs de bord restent visibles.
- **Pas de via USB Ø0,01016 mm / perçage 0,00635 mm** du champ de netclass LEVIA : valeurs inférieures à son propre minimum global. FC_01 utilise provisoirement Ø0,40 mm / perçage 0,25 mm pour cette classe; ce choix est à confirmer avec le fabricant.
- L'empilage physique détaillé de LEVIA n'est pas transposé : FC_01 n'a encore que six couches nommées et une épaisseur totale 1,6 mm. La géométrie USB nominale ne garantit donc pas 90 Ω sur l'empilage du fabricant.
- Les deux zones GND **existantes** gardent leurs propres paramètres (dégagement 0,20 mm, largeur mini 0,20 mm, thermique 0,30 mm); les nouveaux paramètres de zone s'appliquent aux zones créées ultérieurement. Les deux zones doivent être remplies et revues après routage.

## DRC KiCad 10.0.6, avant/après changement de règles

| Type d'erreur | Avant | Après |
|---|---:|---:|
| Dégagement cuivre | 32 | 1 (U4, 0,125 mm réel contre 0,127 mm) |
| Cuivre/bord | 9 | 4 |
| Ponts de masque U12 | 39 | 39 |
| Contour auto-intersecté | 2 | 2 |
| **Total erreurs DRC** | **82** | **46** |
| Connexions non routées | 353 | 353 |

La diminution du nombre d'erreurs provient de règles différentes, **pas d'une modification de cuivre ni d'une preuve de fabricabilité**. Les exigences du fabricant PCB, le plan de l'empreinte U4, l'empilage/impédance USB, le masque du BMP581 et le contour mécanique restent à qualifier avant fabrication.

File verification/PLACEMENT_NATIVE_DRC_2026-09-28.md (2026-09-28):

# Correction des collisions de placement — KiCad 10.0.6 (28/09/2026)

## Changements

- **D3** déplacée de `(105,90 ; 92,10)` à `(103,50 ; 104,00)` sur F.Cu, orientation 90° conservée. Le trou de fixation H1 reste à sa place. Cette zone dégage les courtyards, pads, trous traversants et connecteurs sur les deux faces. Ce déplacement allonge potentiellement la liaison de protection/alimentation `+5V` ↔ `+5V_SYS` : son trajet, sa largeur et la chute de tension doivent être vérifiés pendant le routage.
- **U12 BMP581** : les 20 segments de courtyard, dont plusieurs de longueur nulle et qui se croisaient, sont remplacés par un rectangle fermé `2,6162 × 2,6162 mm`. Correction dans le PCB et dans l'empreinte locale.
- Les **22 positions figées** restent inchangées. Aucune piste ni via n'a été ajoutée.

## Comparaison des contrôles natifs

| KiCad 10.0.6 | Avant | Après |
|---|---:|---:|
| DRC, violations | 519 | **496** |
| DRC, erreurs | 104 | **82** |
| Courts-circuits détectés | 1 (D3/H1, +5V/GND) | **0** |
| Chevauchements de courtyards | 1 (D3/H1) | **0** |
| Courtyard malformé | 19 (U12) | **0** |
| Connexions non routées | 353 | **353** |
| ERC, violations | 341 (23 erreurs, 318 avertissements) | **341** (schéma non modifié) |

Les scripts `verify_design.py` (156 empreintes, 562 couples broche/pad), `check_connectivity.py`, `audit_placement.py` et `audit_through_holes.py` ne signalent pas de nouvelle discordance/collision dans leur périmètre. Le DRC natif fait foi pour les défauts de cuivre et mécanique.

## Défauts encore ouverts

- **32 erreurs de dégagement cuivre** : toutes entre pads d'une même empreinte (U1, U4, U10, U11). Leur correction requiert l'examen des land patterns constructeur ou une règle locale documentée; déplacer ces composants ne peut pas supprimer leurs erreurs internes.
- **39 ponts de masque**, tous liés à la fenêtre B.Mask sous U12. L'ouverture suit la recommandation Bosch de ne pas mettre de masque sous le capteur, mais les ponts entre pads exigent une décision avec l'assembleur et une vérification de production.
- **Deux erreurs de contour Edge.Cuts** (auto-intersections) et **neuf dégagements cuivre/bord**, dont les trous de fixation/connecteurs figés. Le contour mécanique doit être validé avec les dimensions du châssis avant modification.
- La sérigraphie et trois différences entre empreinte embarquée et bibliothèque locale sont encore signalées par KiCad. Le déplacement D3 peut produire des avertissements de sérigraphie près de U2/R31.
- Le PCB reste **non routé**. ERC, DRC et fabricant doivent être revus après corrections et routage. Cette passe ne libère pas la fabrication.

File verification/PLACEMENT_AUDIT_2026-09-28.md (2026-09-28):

# FC_01 — contrôle schéma, empreintes et implantation (28/09/2026)

Base : `b4cfb44959cea596d19cdc92941de7909c9316be` (`main`). Les positions des 22 références figées par Olivier ont été comparées au PCB de cette base.

**Correction ultérieure :** voir [USB_POWER_REWORK_2026-09-28.md](USB_POWER_REWORK_2026-09-28.md). Le contrôle ci-dessous ignorait les trous traversants de USB1 en face des composants F.Cu; les positions U6/D4/C30/R12 décrites ici sont périmées.

[Aperçu corrigé UP/DOWN des courtyards](PLACEMENT_PREVIEW_2026-09-28.png) : gris = position figée, orange = correction après revue graphique. Cette image ne représente ni les pistes ni les couches internes.

## Revue graphique corrective du 28/09

La première version avait laissé **Y1 au dos**, dans l'espace étroit entre USB1 et J12. Cette implantation était mal choisie. Y1 est désormais sur **F.Cu à (94,80 ; 93,00 mm), angle 180°**, du même côté que U2 et dans l'ordre des broches OSC_IN/OSC_OUT. Les distances directes pad à pad sont de 4,13 mm vers U2.12 et 3,19 mm vers U2.13. Le CSTNE8M00GH5C000R0 intègre ses capacités de charge : il n'y a pas de condensateurs externes à ajouter autour de Y1.

Le keepout de cuivre local suit Y1 sur F.Cu; son keepout opposé est désormais sur B.Cu. **C34** a été déplacé à (97,73 ; 90,87 mm) et **R18** à (93,55 ; 91,03 mm) pour libérer ce keepout. C32, R13, C17, C19 et C46 ont été légèrement espacés de leurs voisins. Le contrôle de courtyards ne trouve aucun recouvrement sur une même face et aucun composant B.Cu dans le keepout opposé de Y1. Les 22 composants figés restent inchangés.

La vue reste une vérification de placement 2D : les textes de sérigraphie, l'accès de soudage, les boîtiers réels et les dégagements cuivre ne sont pas validés par ce contrôle. Le routage et un DRC KiCad restent indispensables.

## Résultat reproductible

| Contrôle | Résultat | Limite |
|---|---:|---|
| Références schéma / PCB | 156 / 156 | Contrôle structurel, pas ERC natif |
| Broches numérotées comparées | 562 | Les quatre nets de bus MOTOR1–4 exigent F8/ERC natifs |
| Symbole local et cache schéma | 156 cohérents | Bibliothèque projet `FC01_Project` |
| Pads PCB / empreintes locales | Aucun écart | Numéros, positions, dimensions, forme, orientation, couches et modèles 3D |
| Groupes de nets schéma / PCB | Aucun conflit ni fusion | Bus MOTOR1–4 exclus du parseur statique |
| Courtyards sur la même face | Aucun recouvrement détecté | Test de rectangles englobants, à confirmer par DRC KiCad |
| Keepout opposé Y1 sur B.Cu | Aucun composant dedans | Zone opposée déplacée avec Y1 |
| Positions figées | 22 inchangées | Coordonnées, angles et faces comparés à `main` |
| Segments routés / vias / zones cuivre | 0 / 26 / 2 à la date de cet audit | Les 26 vias ont ensuite été supprimés; voir correction ultérieure |

Commandes : `python tools/verify_design.py`, `python tools/check_connectivity.py` et `python tools/audit_placement.py --baseline <PCB de b4cfb44>`.

## Références figées

`J3 J13 J14 JP1 J8 J9 J11 J10 J7 J6 J4 J5 J1 J2 H1 H2 H3 H4 USB1 U8 U14 J12`.

## Corrections électriques et bibliothèques

- Les nets des deux pads de **R34, R35 et R36** ont été inversés sur le PCB pour refléter le schéma. Les résistances série séparent désormais les nets MCU et IMU.
- Le symbole local **U7 TJA1057GTK/3Z** est synchronisé avec son cache du schéma. L'ancien PDF TJA1051 enregistré comme `U7_datasheet.pdf` a été remplacé par le PDF NXP TJA1057 Rev. 8.1 (02/03/2026). Les prix et stocks hérités du TJA1051 sont supprimés.
- La référence **R51** est `RC0402FR-0722RL` (22 Ω), vérifiée dans sa fiche Yageo archivée sous `R51_datasheet.pdf`. `RC0402FR-07220RL` désigne 220 Ω et ne doit pas être utilisé pour R51. Son offre France reste non confirmée.
- Les orientations des pads PCB ont été resynchronisées depuis les empreintes locales et les associations 3D U10/U11 ont été remises en accord. Les coordonnées des composants figés n'ont pas changé.

## Contrôle croisé des boîtiers critiques

| Références | Fiche archivée / constat dans l'empreinte | Réserve |
|---|---|---|
| U2 | ST STM32H743VIT6, LQFP100 14 × 14 mm, pas 0,5 mm; 100 pads présents | Routage et découplage à vérifier dans KiCad |
| U3 | TI LMR43620, RPE0009B VQFN-HR 2 × 2 mm; neuf pads avec polygones cuivre propres au boîtier | Stencil et vias thermiques à contrôler à l'assemblage |
| U4 | TI LMR60430-Q1, RAK0009A WQFN-HR 2,5 × 2,0 mm; neuf pads propres au boîtier | Boucle SW/PGND et FB à contrôler après routage |
| U5/U6 | Diodes AP7361C-33FGE-7, U-DFN3030-8 Type E; huit pads au pas 0,65 mm et pad 9 de 1,60 × 2,35 mm | Quatre fenêtres de pâte du pad thermique à qualifier |
| L1/L2 | Coilcraft XGL4030, deux pads de 0,98 × 3,40 mm, centres séparés de 2,37 mm | Validation d'assemblage et disponibilité à confirmer |
| U7 | NXP TJA1057GTK/3Z, HVSON8 SOT782-1; pin 5 VIO, pin 9/EP GND | Offre France à reconfirmer; modèle 3D = enveloppe |

Les autres 39 MPN utilisent les preuves classées dans `EVIDENCE.json`, les 36 PDF hachés dans `SOURCE_HASHES.json`, et les dimensions/pins contrôlés par `verify_design.py`. Ce rapprochement ne constitue pas une validation indépendante de chaque spécification électrique ou de chaque tolérance mécanique constructeur. **USB1** reste marqué « plan primaire coté en attente »; les alternatives de pads U1/U10/U11 et le stencil U5/U6 nécessitent une revue de fabrication.

## Déplacements et distances pad à pad

| Liaison | Avant (mm) | Après (mm) |
|---|---:|---:|
| C7.1 → U2.48 VCAP | 1,60 | 1,88 |
| C10.1 → U2.73 VCAP | 2,58 | 1,94 |
| C3.1 → U2.20 VDDA | 21,95 | 1,75 |
| C9.1 → U2.14 NRST | 23,63 | 1,95 |
| C14.1 → U2.21 VDDA | 19,69 | 2,38 |
| C15.1 → U2.20 VDDA | 20,40 | 2,56 |
| Y1.1 → U2.12 OSC_IN | 17,03 | 4,13 |
| Y1.3 → U2.13 OSC_OUT | 17,09 | 3,19 |
| C19.1 → U4.1 VBAT | 3,53 | 1,75 |
| R10.1 → U4.6 FB | 4,05 | 1,22 |

C7 a été reculé de 0,35 mm pour libérer le courtyard du MCU; sa distance électrique augmente de 0,28 mm. Y1 est maintenant côté F.Cu et son keepout opposé est sur B.Cu. Le filtre ADC_AIRSPEED, dont R18 et C34 ont été déplacés, doit être revu au routage. Le nœud SW U4→L2 reste d'environ 4 mm à vol d'oiseau; le réduire davantage demande de réorganiser toute la cellule 9 V et son routage.

## Blocages avant fabrication

KiCad 10 et `kicad-cli` ne sont pas disponibles dans cet environnement : **ERC, F8 et DRC natifs non exécutés**. Le PCB n'a aucun segment routé; les distances ci-dessus ne sont pas des longueurs de piste. Il faut vérifier dans KiCad les keepouts capteurs U9/U12, les dégagements des trous/connecteurs et les plans GND après remplissage, puis router et exécuter DRC. Ne pas lancer de fabrication sur ce seul audit statique.

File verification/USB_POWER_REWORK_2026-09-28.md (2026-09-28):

# FC_01 — correction USB1 / U6 et vias (28/09/2026)

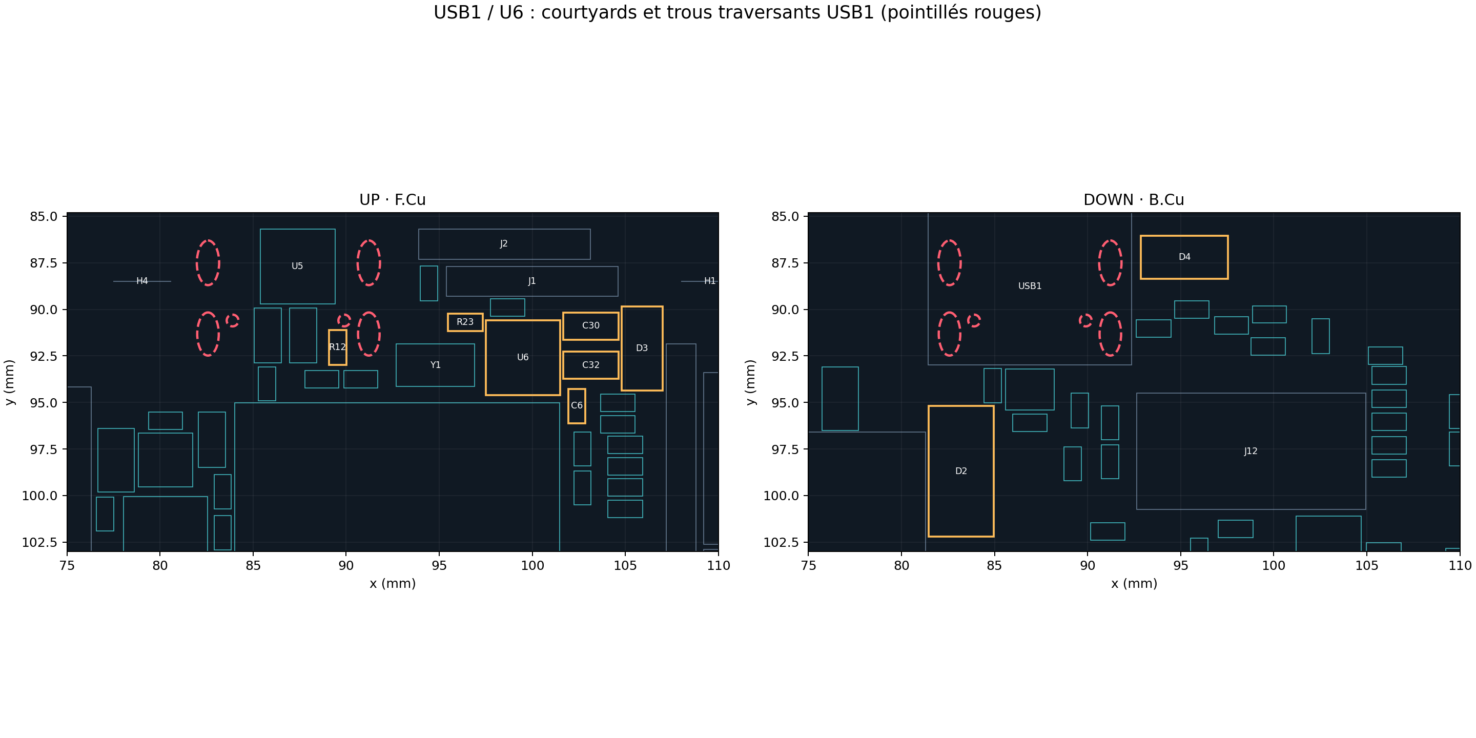
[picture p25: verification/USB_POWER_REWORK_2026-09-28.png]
Courtyards UP/DOWN et trous traversants USB1


La vérification précédente comparait les courtyards **sur une seule face**. Elle a manqué les trous traversants de USB1 sous des composants de F.Cu. Avant correction, les fixations GND de USB1 recouvraient les pads de D4 (`VBUS`, `+5V_SYS`) et C30 (`+5V_SYS`), et SH6 traversait le pad central de U6. Un trou non métallisé tombait aussi sous R12. Le PCB précédent n'était pas utilisable.

| Référence | Implantation corrigée | Raison |
|---|---|---|
| USB1 | Inchangé, B.Cu | Connecteur figé par Olivier. |
| U6 | F.Cu (99,50 ; 92,60), 180° | Libère SH6; sortie +3V3_SENS orientée vers C32. |
| C32 | F.Cu (103,15 ; 93,00), 0° | Découplage sortie U6 à environ 1,6 mm pad à pad. |
| C30 | F.Cu (103,15 ; 90,90), 0° | Écarte le pad +5V_SYS de SH4. **Sa distance de l'entrée U6 est d'environ 5 mm; la boucle d'alimentation reste à revoir au routage.** |
| C6, D3, R23 | (102,40 ; 95,20), (105,90 ; 92,10), (96,40 ; 90,70) | Dégagent la nouvelle emprise de U6 et de ses condensateurs. |
| D4 | B.Cu (95,20 ; 87,20), 180° | Ses deux pads ne recouvrent plus les fixations GND de USB1. |
| R12 | F.Cu (89,55 ; 92,05) | Dégage le trou de positionnement USB1. |
| D2 | B.Cu (83,20 ; 98,70), 90° | Dégage la fixation SH3 de USB1. |
| R41–R46 | Décalées de +0,80 mm en y | Dégagent le trou de montage H1. |

Les **26 vias préplacés** ont été supprimés : 22 vias GND périphériques et quatre autres vias de nets divers. Ils n'étaient reliés à aucune piste; les placer avant le routage créait une fausse impression d'avancement et pouvait gêner les nouvelles empreintes. Il reste **0 piste, 0 via et 2 zones cuivre**. Les vias GND utiles seront positionnés après routage et remplissage des plans.

## Contrôles effectués

- `python tools/verify_design.py` : 156 références, 562 couples broche/pad, aucune erreur de géométrie d'empreinte.
- `python tools/check_connectivity.py` : aucun conflit ni fusion des groupes de nets examinés; les bus MOTOR1–4 restent hors du parseur statique.
- `python tools/audit_placement.py --baseline <PCB initial>` : aucun recouvrement de courtyards sur une même face, keepout opposé de Y1 libre, 22 composants figés inchangés.
- `python tools/audit_through_holes.py` : aucun trou traversant d'une face n'intersecte le courtyard d'un composant de l'autre face dans le modèle 2D; aucun contact entre pad SMD et trou traversant détecté.

**Limites :** KiCad CLI n'est pas disponible ici. ERC, DRC natif, remplissage des zones, contrôle 3D du boîtier USB et vérification des dégagements de fabrication restent à faire. Le routage complet est absent. La distance C30–U6 et les liaisons VBUS/+5V_SYS, +3V3_SENS, GND et VCAP exigent une revue de placement/routage avant fabrication.

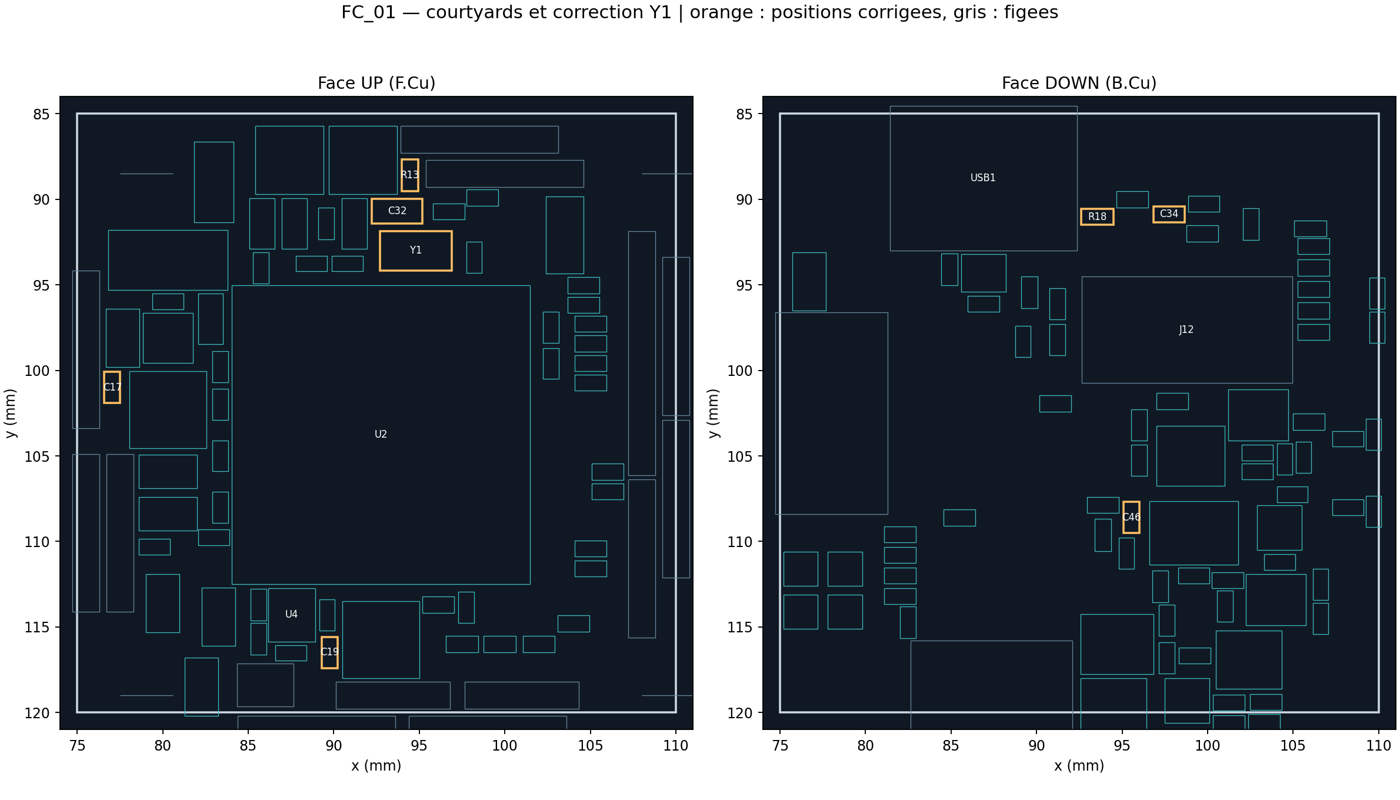
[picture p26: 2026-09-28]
verification/PLACEMENT_PREVIEW_2026-09-28.png

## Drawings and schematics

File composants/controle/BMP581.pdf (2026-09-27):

# BMP581

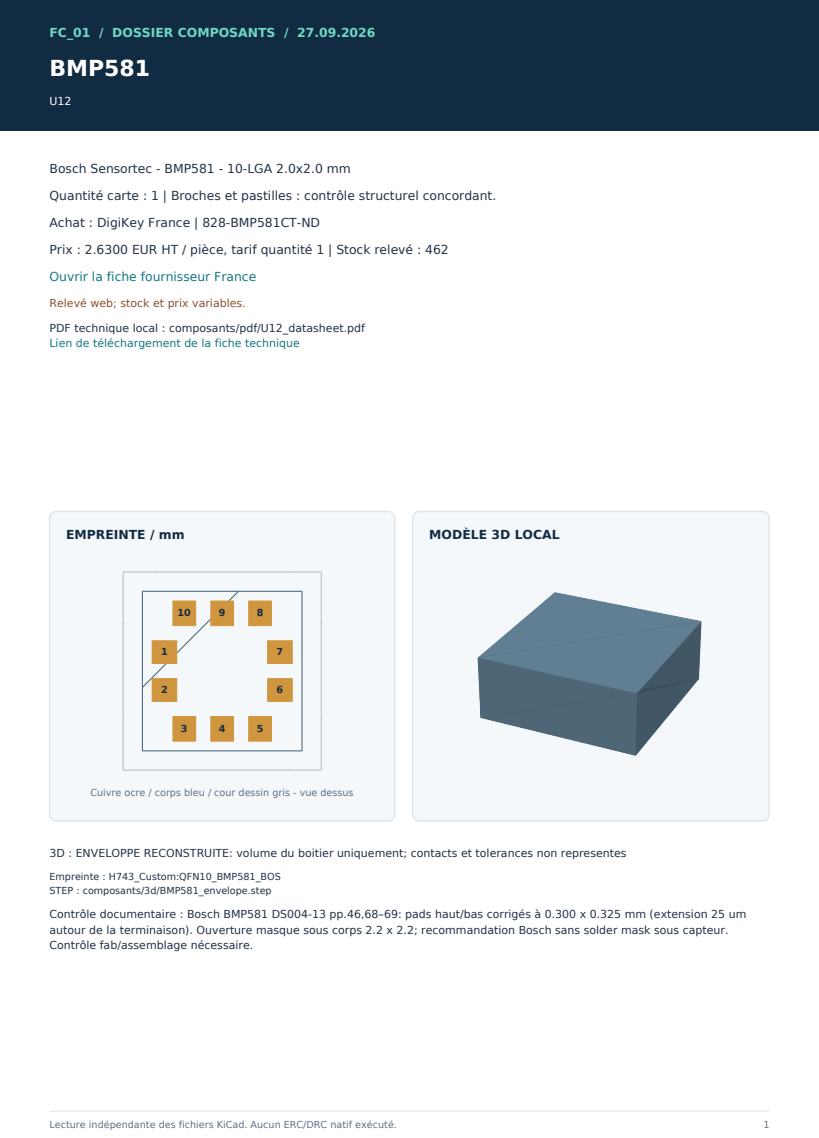
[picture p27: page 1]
FC_01 / DOSSIER COMPOSANTS / 27.09.2026; EMPREINTE / mm; MODÈLE 3D LOCAL; Lecture indépendante des fichiers KiCad. Aucun ERC/DRC natif exécuté.

Bosch Sensortec - BMP581 - 10-LGA 2.0x2.0 mm

Quantité carte : 1 | Broches et pastilles : contrôle structurel concordant.

Achat : DigiKey France | 828-BMP581CT-ND

Prix : 2.6300 EUR HT / pièce, tarif quantité 1 | Stock relevé : 462

Ouvrir la fiche fournisseur France (https://www.digikey.fr/fr/products/detail/bosch-sensortec/BMP581/16036134)

Relevé web; stock et prix variables.

PDF technique local : composants/pdf/U12_datasheet.pdf
Lien de téléchargement de la fiche technique (https://www.bosch-sensortec.com/media/boschsensortec/downloads/datasheets/bst-bmp581-ds004.pdf)

Cuivre ocre / corps bleu / cour dessin gris - vue dessus

3D : ENVELOPPE RECONSTRUITE: volume du boitier uniquement; contacts et tolerances non representes

Empreinte : H743_Custom:QFN10_BMP581_BOS
STEP : composants/3d/BMP581_envelope.step

Contrôle documentaire : Bosch BMP581 DS004-13 pp.46,68–69: pads haut/bas corrigés à 0.300 x 0.325 mm (extension 25 um
autour de la terminaison). Ouverture masque sous corps 2.2 x 2.2; recommandation Bosch sans solder mask sous capteur.
Contrôle fab/assemblage nécessaire.

FC_01 / DOSSIER COMPOSANTS / 27.09.2026

# BMP581

SYMBOLE / FC01_Project:SENSORS__BMP581

Repères : U12

SYMBOLE / CORPS ET NUMÉROS DES BROCHES

1
VDDIO

2
SCK

3
VSS

4
SDI

5

SDO | 6
CSB
| 7
INT
| 8
VSS
| 9
VSS

10 VDD

Correspondance complète : verification/PINS.csv

Rendu vectoriel de la variante utilisée; champs de nomenclature en page précédente. | 2

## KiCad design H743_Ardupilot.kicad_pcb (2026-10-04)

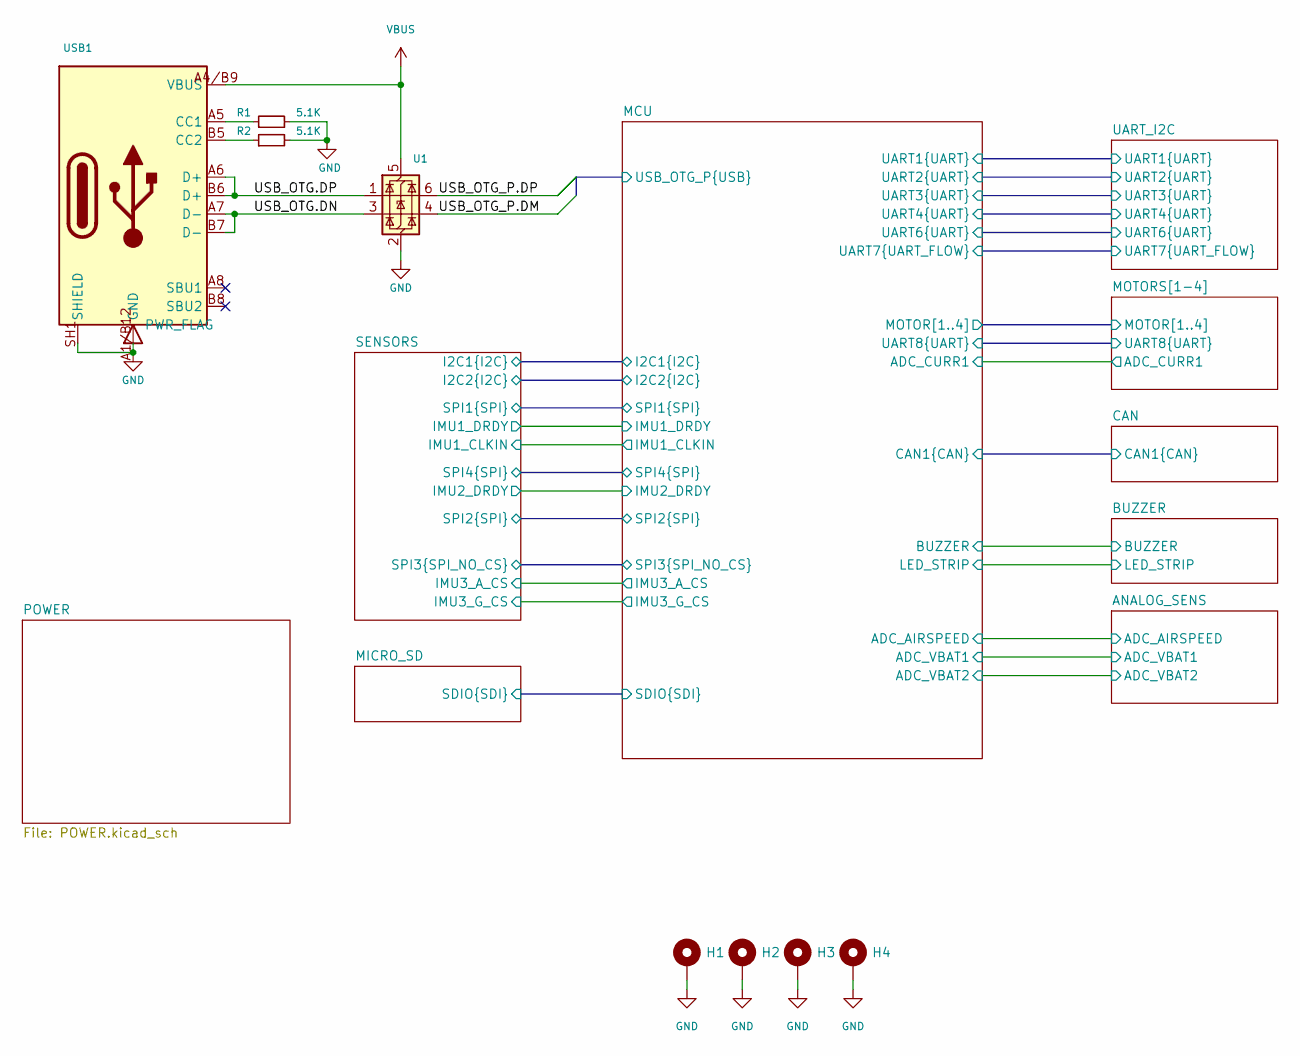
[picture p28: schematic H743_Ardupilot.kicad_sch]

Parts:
H1, H2, H3, H4: MountingHole_Pad; MountingHole_3.2mm_M3_ISO7380_Pad; DigiKey Status Element PCB; aucun composant achete
R1, R2: 5.1K; R_0402_1005Metric; MPN 0402WGF5101TCE; LCSC Part C25905
U1: USBLC6-2P6; SOT50P160X60-6N; MPN USBLC6-2P6; mouser 511-USBLC6-2P6
USB1: DX07S016JA1R1500; JAE_DX07S016JA1R1500_16P; MPN DX07S016JA1R1500; DigiKey Part Number 670-DX07S016JA1R1500CT-ND

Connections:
/MCU/USB_OTG_P.DM: U1.4 (I/O2); also elsewhere on the board
/MCU/USB_OTG_P.DP: U1.6 (I/O1); also elsewhere on the board
/USB_OTG.DN: U1.3 (I/O2), USB1.A7 (D-), USB1.B7 (D-)
/USB_OTG.DP: U1.1 (I/O1), USB1.A6 (D+), USB1.B6 (D+)
GND: H1.1 (1_1), H2.1 (1_1), H3.1 (1_1), H4.1 (1_1), R1.2, R2.2, U1.2 (GND), USB1.A1/B12 (GND), USB1.A12/B1 (GND), USB1.SH1 (SHIELD), USB1.SH2 (SHIELD), USB1.SH3 (SHIELD), USB1.SH4 (SHIELD), USB1.SH5 (SHIELD), USB1.SH6 (SHIELD); also elsewhere on the board
unnamed: R1.1, USB1.A5 (CC1)
unnamed: R2.1, USB1.B5 (CC2)
VBUS: U1.5 (VBUS), USB1.A4/B9 (VBUS), USB1.B4/A9 (VBUS); also elsewhere on the board

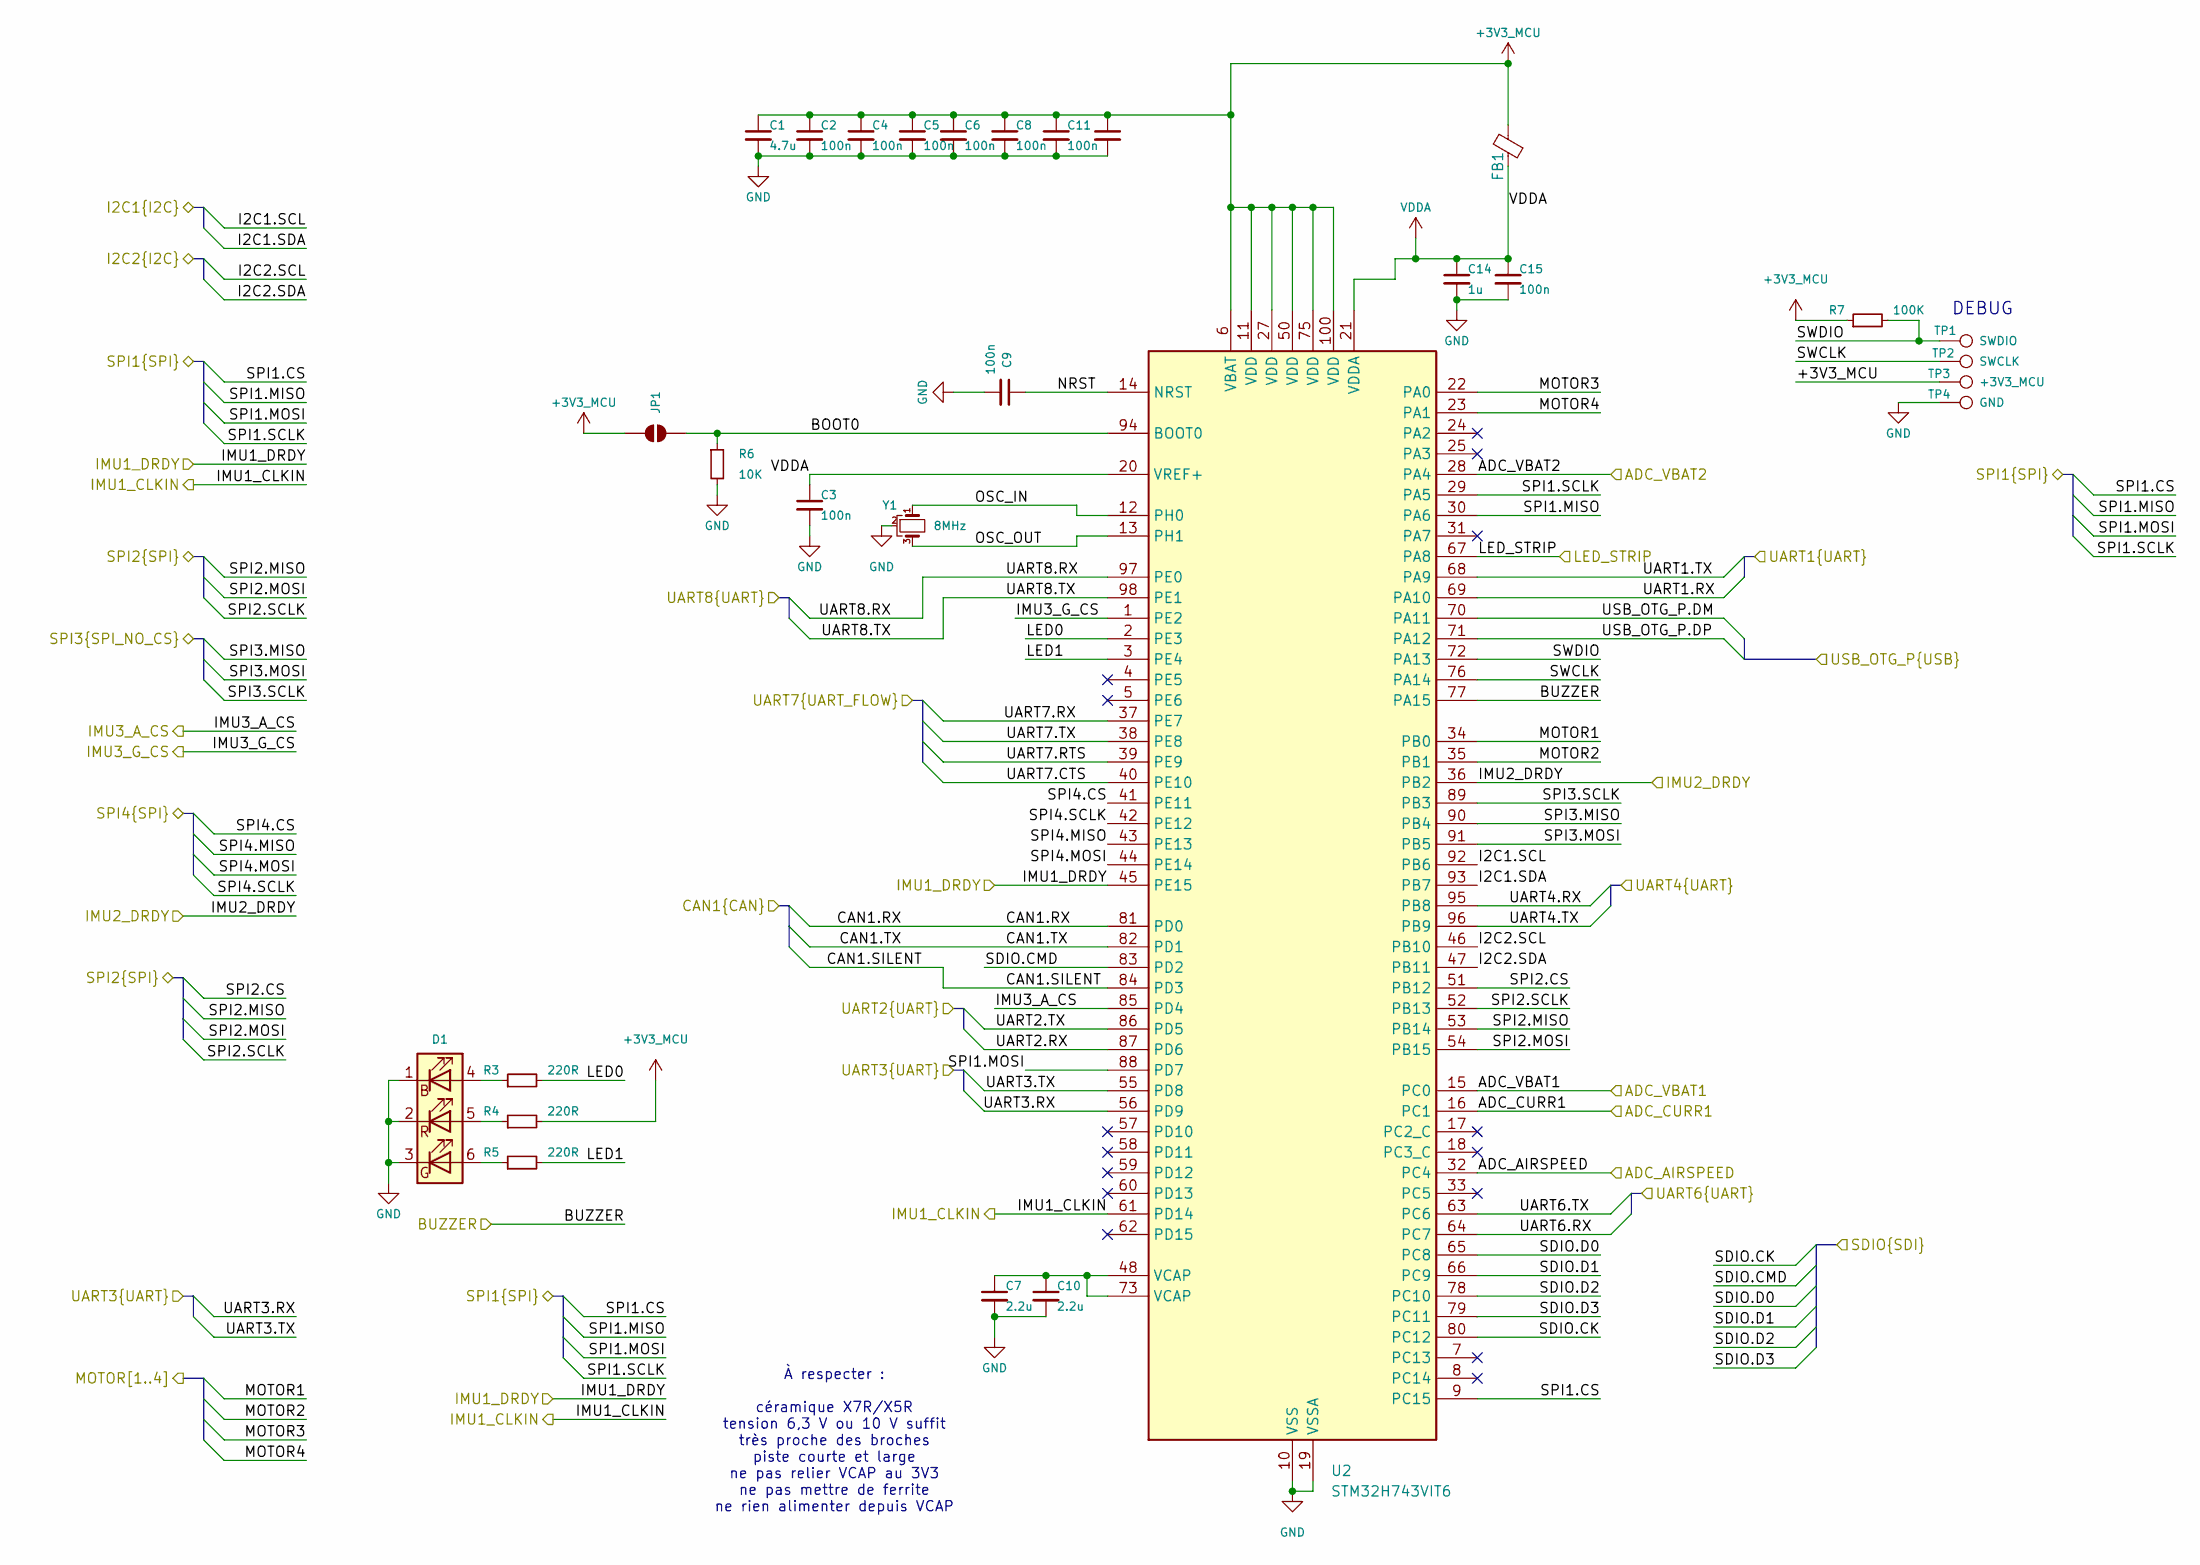
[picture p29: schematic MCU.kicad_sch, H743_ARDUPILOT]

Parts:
C1: 4.7u; C_0402_1005Metric; MPN CL05A475MP5NRNC; DigiKey Part Number 1276-1482-1-ND
C2, C3, C4, C5, C6, C8, C9, C11, C12, C15: 100n; C_0402_1005Metric; MPN CL05B104KO5NNNC; DigiKey Part Number 1276-1001-1-ND
C7, C10: 2.2u; C_0402_1005Metric; MPN C1005X5R1C225M050BC; DigiKey Specs 2.2 µF ±20%, 16 V, X5R, 0402
C14: 1u; C_0402_1005Metric; MPN CL05A105KA5NQNC; DigiKey Part Number 1276-1445-1-ND
D1: 19-337/R6GHBHC-M01/2T; Everlight_19-337_1.6x1.6mm; MPN 19-337/R6GHBHC-M01/2T; LCSC Part C131204
FB1: 600Ω@100MHz; L_0402_1005Metric; MPN BLM15AG601SN1D; DigiKey Part Number 490-1006-1-ND
JP1: SolderJumper_2_Open; SolderJumper-2_P1.3mm_Open_RoundedPad1.0x1.5mm; DigiKey Status Element PCB; aucun composant achete
R3, R4, R5: 220R; R_0402_1005Metric; MPN RC0402FR-07220RL; DigiKey Specs 220 Ω ±1%, 0402
R6: 10K; R_0402_1005Metric; MPN RC0402FR-0710KL; DigiKey Specs 10 kΩ ±1%, 0402
R7: 100K; R_0402_1005Metric; MPN RC0402FR-07100KL; DigiKey Specs 100 kΩ ±1%, 0402
TP1: SWDIO; TestPoint_Pad_1.0x1.0mm; DigiKey Status Element PCB; aucun composant achete
TP2: SWCLK; TestPoint_Pad_1.0x1.0mm; DigiKey Status Element PCB; aucun composant achete
TP3: +3V3_MCU; TestPoint_Pad_1.0x1.0mm; DigiKey Status Element PCB; aucun composant achete
TP4: GND; TestPoint_Pad_1.0x1.0mm; DigiKey Status Element PCB; aucun composant achete
U2: STM32H743VIT6; LQFP-100_14x14mm_P0.5mm; MPN STM32H743VIT6; DigiKey Part Number 497-17720-ND
Y1: 8MHz; Murata_CSTNE_3.2x1.3_P1.2mm; MPN CSTNE8M00GH5C000R0; LCSC Part C341525

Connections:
+3V3_MCU: C1.1, C2.1, C4.1, C5.1, C6.1, C8.1, C11.1, C12.1, FB1.2, JP1.2 (B), R4.2, R7.1, TP3.1 (1_1), U2.6 (VBAT), U2.11 (VDD), U2.27 (VDD), U2.50 (VDD), U2.75 (VDD), U2.100 (VDD); also elsewhere on the board
/ANALOG_SENS/ADC_AIRSPEED: U2.32 (PC4); also elsewhere on the board
/ANALOG_SENS/ADC_VBAT1: U2.15 (PC0); also elsewhere on the board
/ANALOG_SENS/ADC_VBAT2: U2.28 (PA4); also elsewhere on the board
/BUZZER/BUZZER: U2.77 (PA15); also elsewhere on the board
/BUZZER/LED_STRIP: U2.67 (PA8); also elsewhere on the board
/CAN/CAN1.RX: U2.81 (PD0); also elsewhere on the board
/CAN/CAN1.SILENT: U2.84 (PD3); also elsewhere on the board
/CAN/CAN1.TX: U2.82 (PD1); also elsewhere on the board
/MCU/ADC_CURR1: U2.16 (PC1); also elsewhere on the board
/MCU/BOOT0: JP1.1 (A), R6.1, U2.94 (BOOT0)
/MCU/I2C1.SCL: U2.92 (PB6); also elsewhere on the board
/MCU/I2C1.SDA: U2.93 (PB7); also elsewhere on the board
/MCU/I2C2.SCL: U2.46 (PB10); also elsewhere on the board
/MCU/I2C2.SDA: U2.47 (PB11); also elsewhere on the board
/MCU/IMU1_CLKIN: U2.61 (PD14); also elsewhere on the board
/MCU/IMU1_DRDY: U2.45 (PE15); also elsewhere on the board
/MCU/IMU2_DRDY: U2.36 (PB2); also elsewhere on the board
/MCU/IMU3_A_CS: U2.85 (PD4); also elsewhere on the board
/MCU/IMU3_G_CS: U2.1 (PE2); also elsewhere on the board
/MCU/LED0: R3.2, U2.2 (PE3)
/MCU/LED1: R5.2, U2.3 (PE4)
/MCU/MOTOR1: U2.34 (PB0); also elsewhere on the board
/MCU/MOTOR2: U2.35 (PB1); also elsewhere on the board
/MCU/MOTOR3: U2.22 (PA0); also elsewhere on the board
/MCU/MOTOR4: U2.23 (PA1); also elsewhere on the board
/MCU/NRST: C9.1, U2.14 (NRST)
/MCU/OSC_IN: U2.12 (PH0), Y1.1
/MCU/OSC_OUT: U2.13 (PH1), Y1.3
/MCU/SDIO.CK: U2.80 (PC12); also elsewhere on the board
/MCU/SDIO.CMD: U2.83 (PD2); also elsewhere on the board
/MCU/SDIO.D0: U2.65 (PC8); also elsewhere on the board
/MCU/SDIO.D1: U2.66 (PC9); also elsewhere on the board
/MCU/SDIO.D2: U2.78 (PC10); also elsewhere on the board
/MCU/SDIO.D3: U2.79 (PC11); also elsewhere on the board
/MCU/SPI1.CS: U2.9 (PC15); also elsewhere on the board
/MCU/SPI1.MISO: U2.30 (PA6); also elsewhere on the board
/MCU/SPI1.MOSI: U2.88 (PD7); also elsewhere on the board
/MCU/SPI1.SCLK: U2.29 (PA5); also elsewhere on the board
/MCU/SPI2.CS: U2.51 (PB12); also elsewhere on the board
/MCU/SPI2.MISO: U2.53 (PB14); also elsewhere on the board
/MCU/SPI2.MOSI: U2.54 (PB15); also elsewhere on the board
/MCU/SPI2.SCLK: U2.52 (PB13); also elsewhere on the board
/MCU/SPI3.MISO: U2.90 (PB4); also elsewhere on the board
/MCU/SPI3.MOSI: U2.91 (PB5); also elsewhere on the board
/MCU/SPI3.SCLK: U2.89 (PB3); also elsewhere on the board
/MCU/SPI4.CS: U2.41 (PE11); also elsewhere on the board
/MCU/SPI4.MISO: U2.43 (PE13); also elsewhere on the board
/MCU/SPI4.MOSI: U2.44 (PE14); also elsewhere on the board
/MCU/SPI4.SCLK: U2.42 (PE12); also elsewhere on the board
/MCU/SWCLK: TP2.1 (1_1), U2.76 (PA14)
/MCU/SWDIO: R7.2, TP1.1 (1_1), U2.72 (PA13)
/MCU/UART1.RX: U2.69 (PA10); also elsewhere on the board
/MCU/UART1.TX: U2.68 (PA9); also elsewhere on the board
/MCU/UART2.RX: U2.87 (PD6); also elsewhere on the board
/MCU/UART2.TX: U2.86 (PD5); also elsewhere on the board
/MCU/UART3.RX: U2.56 (PD9); also elsewhere on the board
/MCU/UART3.TX: U2.55 (PD8); also elsewhere on the board
/MCU/UART4.RX: U2.95 (PB8); also elsewhere on the board
/MCU/UART4.TX: U2.96 (PB9); also elsewhere on the board
/MCU/UART6.RX: U2.64 (PC7); also elsewhere on the board
/MCU/UART6.TX: U2.63 (PC6); also elsewhere on the board
/MCU/UART7.CTS: U2.40 (PE10); also elsewhere on the board
/MCU/UART7.RTS: U2.39 (PE9); also elsewhere on the board
/MCU/UART7.RX: U2.37 (PE7); also elsewhere on the board
/MCU/UART7.TX: U2.38 (PE8); also elsewhere on the board
/MCU/UART8.RX: U2.97 (PE0); also elsewhere on the board
/MCU/UART8.TX: U2.98 (PE1)
/MCU/USB_OTG_P.DM: U2.70 (PA11); also elsewhere on the board
/MCU/USB_OTG_P.DP: U2.71 (PA12); also elsewhere on the board
GND: C1.2, C2.2, C3.2, C4.2, C5.2, C6.2, C7.2, C8.2, C9.2, C10.2, C11.2, C12.2, C14.2, C15.2, D1.1 (BK), D1.2 (RK), D1.3 (GK), R6.2, TP4.1 (1_1), U2.10 (VSS), U2.19 (VSSA), U2.26 (VSS), U2.49 (VSS), U2.74 (VSS), U2.99 (VSS), Y1.2; also elsewhere on the board
unnamed: C7.1, C10.1, U2.48 (VCAP), U2.73 (VCAP)
unnamed: D1.4 (BA), R3.1
unnamed: D1.6 (GA), R5.1
unnamed: D1.5 (RA), R4.1
VDDA: C3.1, C14.1, C15.1, FB1.1, U2.20 (VREF+), U2.21 (VDDA)

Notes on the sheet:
DEBUG
À respecter : céramique X7R/X5R tension 6,3 V ou 10 V suffit très proche des broches piste courte et large ne pas relier VCAP au 3V3 ne pas mettre de ferrite ne rien alimenter depuis VCAP

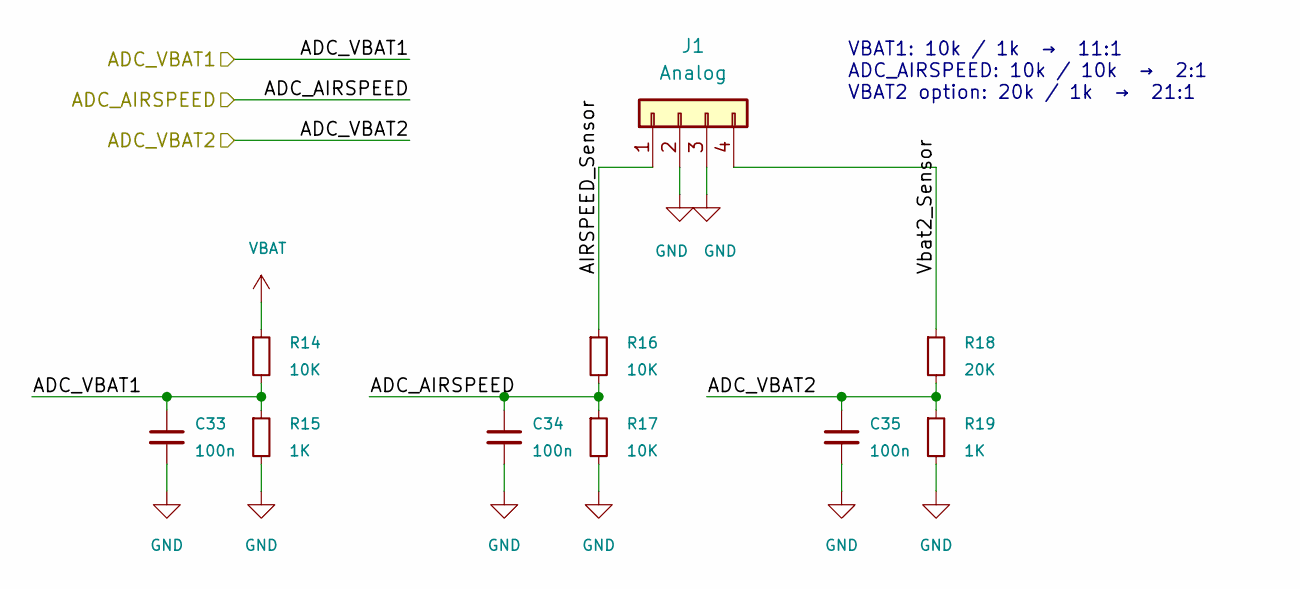
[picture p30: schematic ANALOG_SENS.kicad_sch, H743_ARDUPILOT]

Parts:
C33, C34, C35: 100n; C_0402_1005Metric; MPN CL05B104KO5NNNC; DigiKey Part Number 1276-1001-1-ND
J1: Analog; SolderPadArray_1x04_P2.54mm_1x1mm; DigiKey Status Element PCB; aucun composant achete
R14, R16, R17: 10K; R_0402_1005Metric; MPN RC0402FR-0710KL; DigiKey Specs 10 kΩ ±1%, 0402
R15, R19: 1K; R_0402_1005Metric; MPN RC0402FR-071KL; DigiKey Specs 1 kΩ ±1%, 0402
R18: 20K; R_0402_1005Metric; MPN RC0402FR-0720KL; DigiKey Specs 20 kΩ ±1%, 0402

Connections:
/ANALOG_SENS/ADC_AIRSPEED: C34.1, R16.2, R17.1; also elsewhere on the board
/ANALOG_SENS/ADC_VBAT1: C33.1, R14.2, R15.1; also elsewhere on the board
/ANALOG_SENS/ADC_VBAT2: C35.1, R18.2, R19.1; also elsewhere on the board
/ANALOG_SENS/AIRSPEED_Sensor: J1.1, R16.1
/ANALOG_SENS/Vbat2_Sensor: J1.4, R18.1
GND: C33.2, C34.2, C35.2, J1.2, J1.3, R15.2, R17.2, R19.2; also elsewhere on the board
VBAT: R14.1; also elsewhere on the board

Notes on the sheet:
VBAT1: 10k / 1k → 11:1 ADC_AIRSPEED: 10k / 10k → 2:1 VBAT2 option: 20k / 1k → 21:1

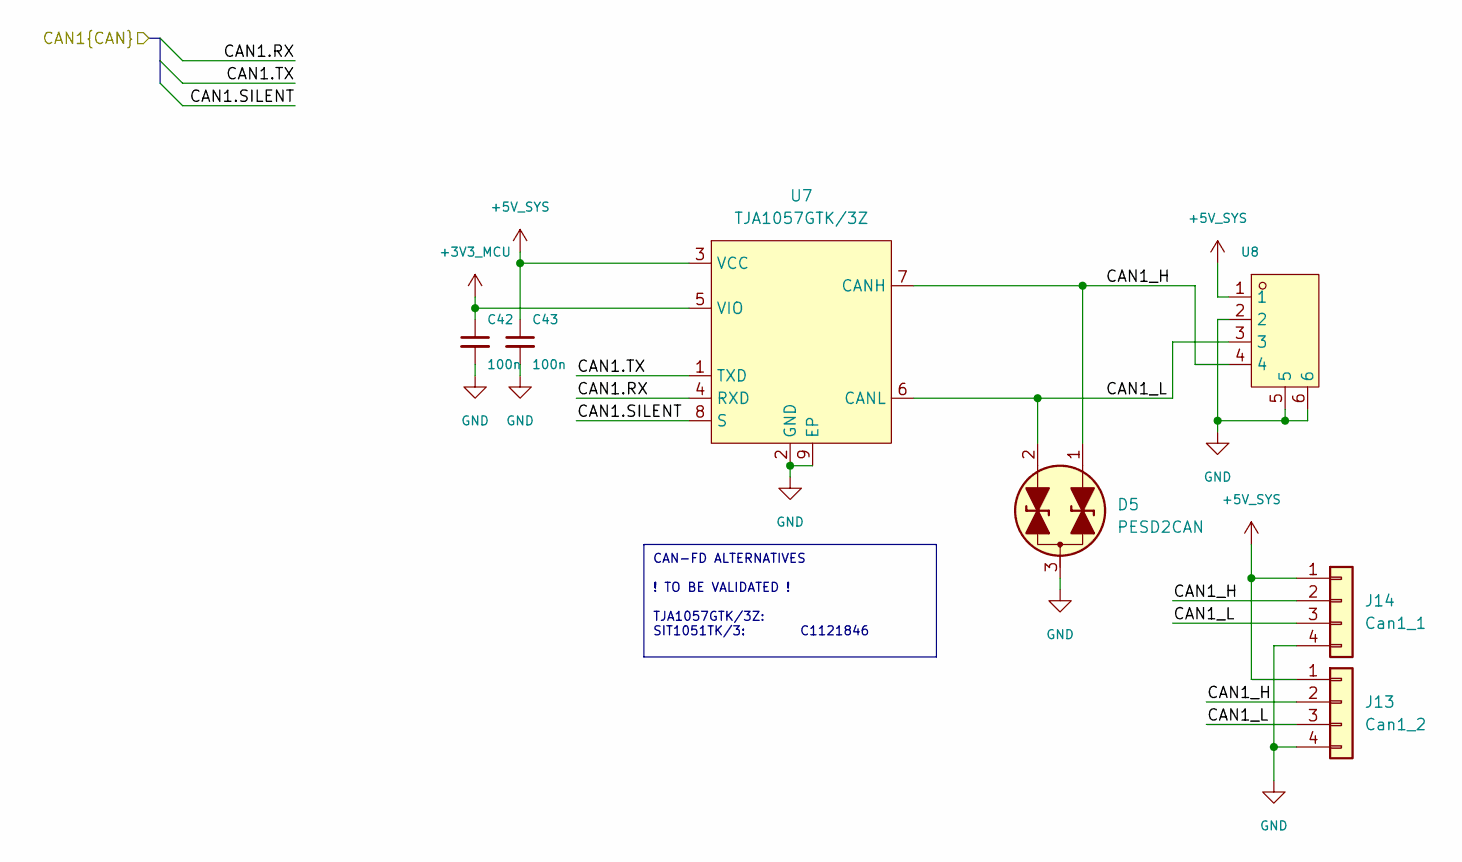
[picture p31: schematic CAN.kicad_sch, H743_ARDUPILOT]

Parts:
C42, C43: 100n; C_0402_1005Metric; MPN CL05B104KO5NNNC; DigiKey Part Number 1276-1001-1-ND
D5: PESD2CAN; SOT-23; MPN PESD2CANFD24V-TR; LCSC Part C552486
J13: Can1_2; SolderPadArray_1x04_P2.54mm_1x1mm; DigiKey Status Element PCB; aucun composant achete
J14: Can1_1; SolderPadArray_1x04_P2.54mm_1x1mm; DigiKey Status Element PCB; aucun composant achete
U7: TJA1057GTK/3Z; HVSON-8-1EP_3x3mm_P0.65mm_EP1.6x2.4mm; MPN TJA1057GTK/3Z; DigiKey Specs CAN 5 Mbps, 4.5–5.5 V, 8-HVSON 3x3
U8: SM04B-GHS-TB(LF)(SN); JST_GH_SM04B-GHS-TB_1x04_P1.25mm_Horizontal_GNDtabs; MPN SM04B-GHS-TB(LF)(SN); LCSC Part C7430446

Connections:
+3V3_MCU: C42.1, U7.5 (VIO); also elsewhere on the board
+5V_SYS: C43.1, J13.1, J14.1, U7.3 (VCC), U8.1; also elsewhere on the board
/CAN/CAN1.RX: U7.4 (RXD); also elsewhere on the board
/CAN/CAN1.SILENT: U7.8 (S); also elsewhere on the board
/CAN/CAN1.TX: U7.1 (TXD); also elsewhere on the board
/CAN/CAN1_H: D5.1 (K1), J13.2, J14.2, U7.7 (CANH), U8.4
/CAN/CAN1_L: D5.2 (K2), J13.3, J14.3, U7.6 (CANL), U8.3
GND: C42.2, C43.2, D5.3 (CC), J13.4, J14.4, U7.2 (GND), U7.9 (EP), U8.2, U8.5, U8.6; also elsewhere on the board

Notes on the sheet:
CAN-FD ALTERNATIVES ! TO BE VALIDATED ! TJA1057GTK/3Z: SIT1051TK/3: C1121846

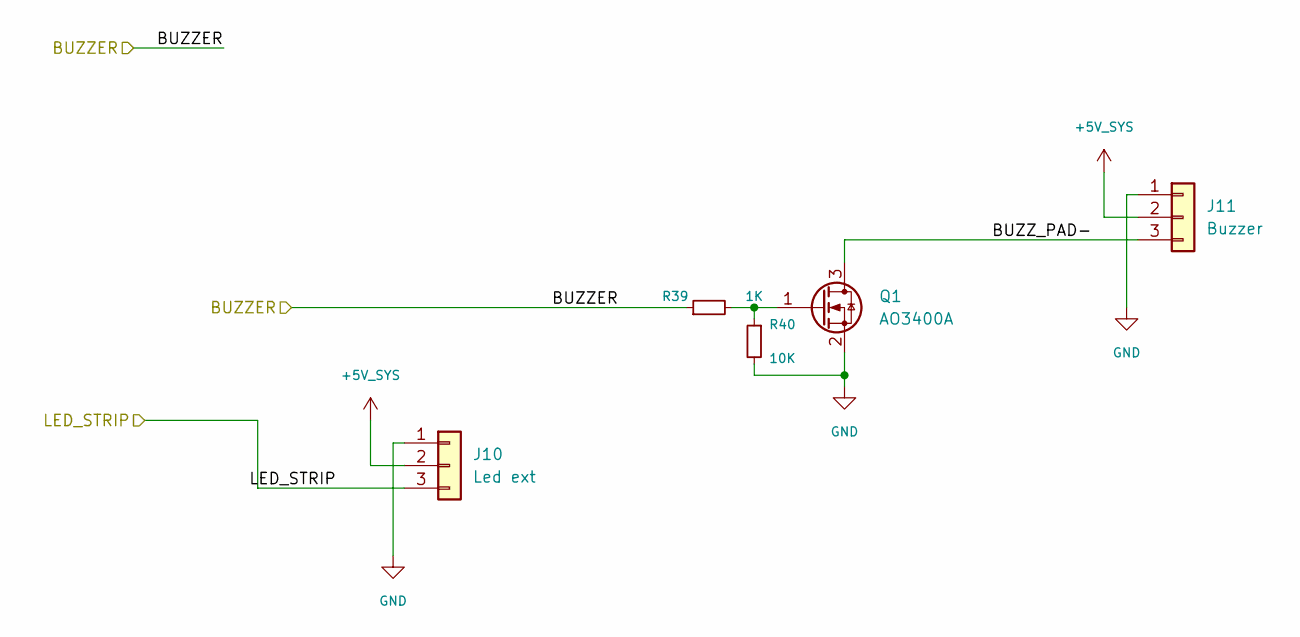
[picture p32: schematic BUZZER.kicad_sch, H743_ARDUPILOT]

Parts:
J10: Led ext; SolderPadArray_1x03_P2.54mm_1x1mm; DigiKey Status Element PCB; aucun composant achete
J11: Buzzer; SolderPadArray_1x03_P2.54mm_1x1mm; DigiKey Status Element PCB; aucun composant achete
Q1: AO3400A; SOT-23; MPN AO3400A; LCSC Part C20917
R39: 1K; R_0402_1005Metric; MPN RC0402FR-071KL; DigiKey Specs 1K ±1%, 0402 (1005), thick film
R40: 10K; R_0402_1005Metric; MPN RC0402FR-0710KL; DigiKey Specs 10K ±1%, 0402 (1005), thick film

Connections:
+5V_SYS: J10.2, J11.2; also elsewhere on the board
/BUZZER/BUZZER: R39.1; also elsewhere on the board
/BUZZER/BUZZ_PAD-: J11.3, Q1.3 (D)
/BUZZER/LED_STRIP: J10.3; also elsewhere on the board
GND: J10.1, J11.1, Q1.2 (S), R40.2; also elsewhere on the board
unnamed: Q1.1 (G), R39.2, R40.1

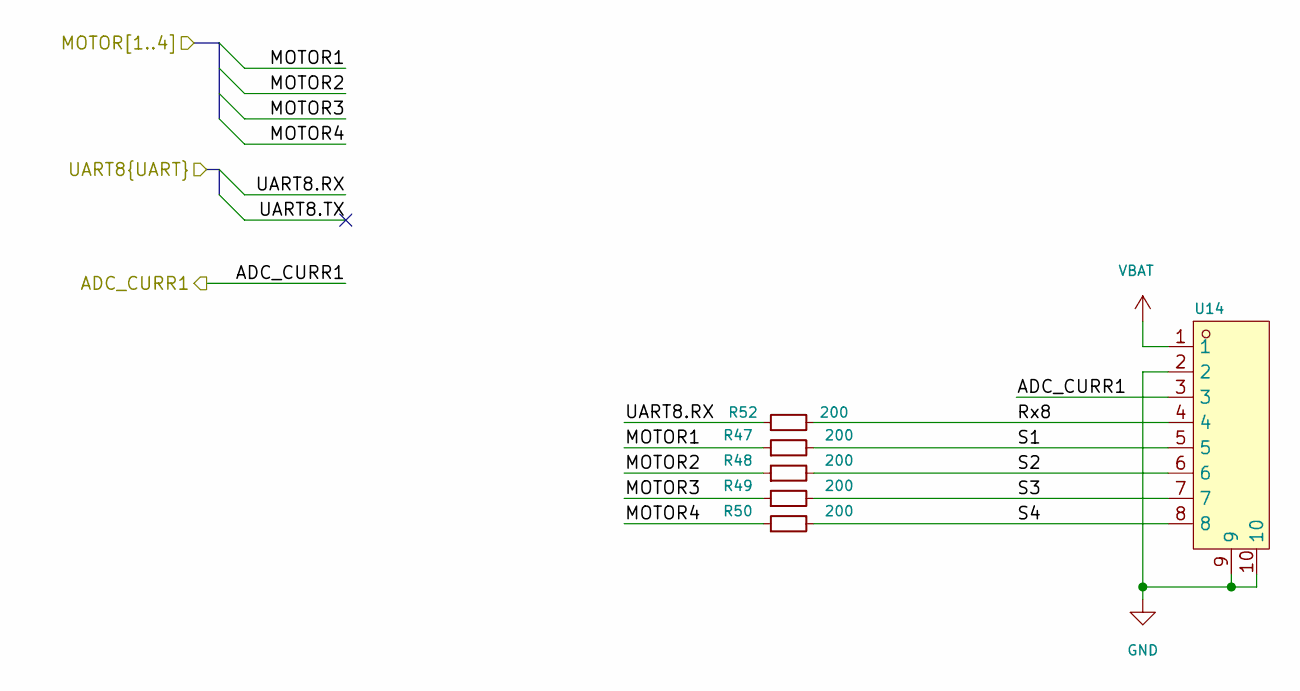
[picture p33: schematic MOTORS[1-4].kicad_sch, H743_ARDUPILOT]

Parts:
R47, R48, R49, R50, R52: 200; R_0402_1005Metric; MPN RC0402FR-07200RL; DigiKey Specs 200 ±1%, 0402 (1005), thick film
U14: SM08B-SRSS-TB(LF)(SN); JST_SH_SM08B-SRSS-TB_1x08_P1.00mm_Horizontal_GNDtabs; MPN SM08B-SRSS-TB(LF)(SN); LCSC Part C7430450

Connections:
/MCU/ADC_CURR1: U14.3; also elsewhere on the board
/MCU/MOTOR1: R47.1; also elsewhere on the board
/MCU/MOTOR2: R48.1; also elsewhere on the board
/MCU/MOTOR3: R49.1; also elsewhere on the board
/MCU/MOTOR4: R50.1; also elsewhere on the board
/MCU/UART8.RX: R52.1; also elsewhere on the board
/MOTORS[1-4]/Rx8: R52.2, U14.4
/MOTORS[1-4]/S1: R47.2, U14.5
/MOTORS[1-4]/S2: R48.2, U14.6
/MOTORS[1-4]/S3: R49.2, U14.7
/MOTORS[1-4]/S4: R50.2, U14.8
GND: U14.2, U14.9, U14.10; also elsewhere on the board
VBAT: U14.1; also elsewhere on the board

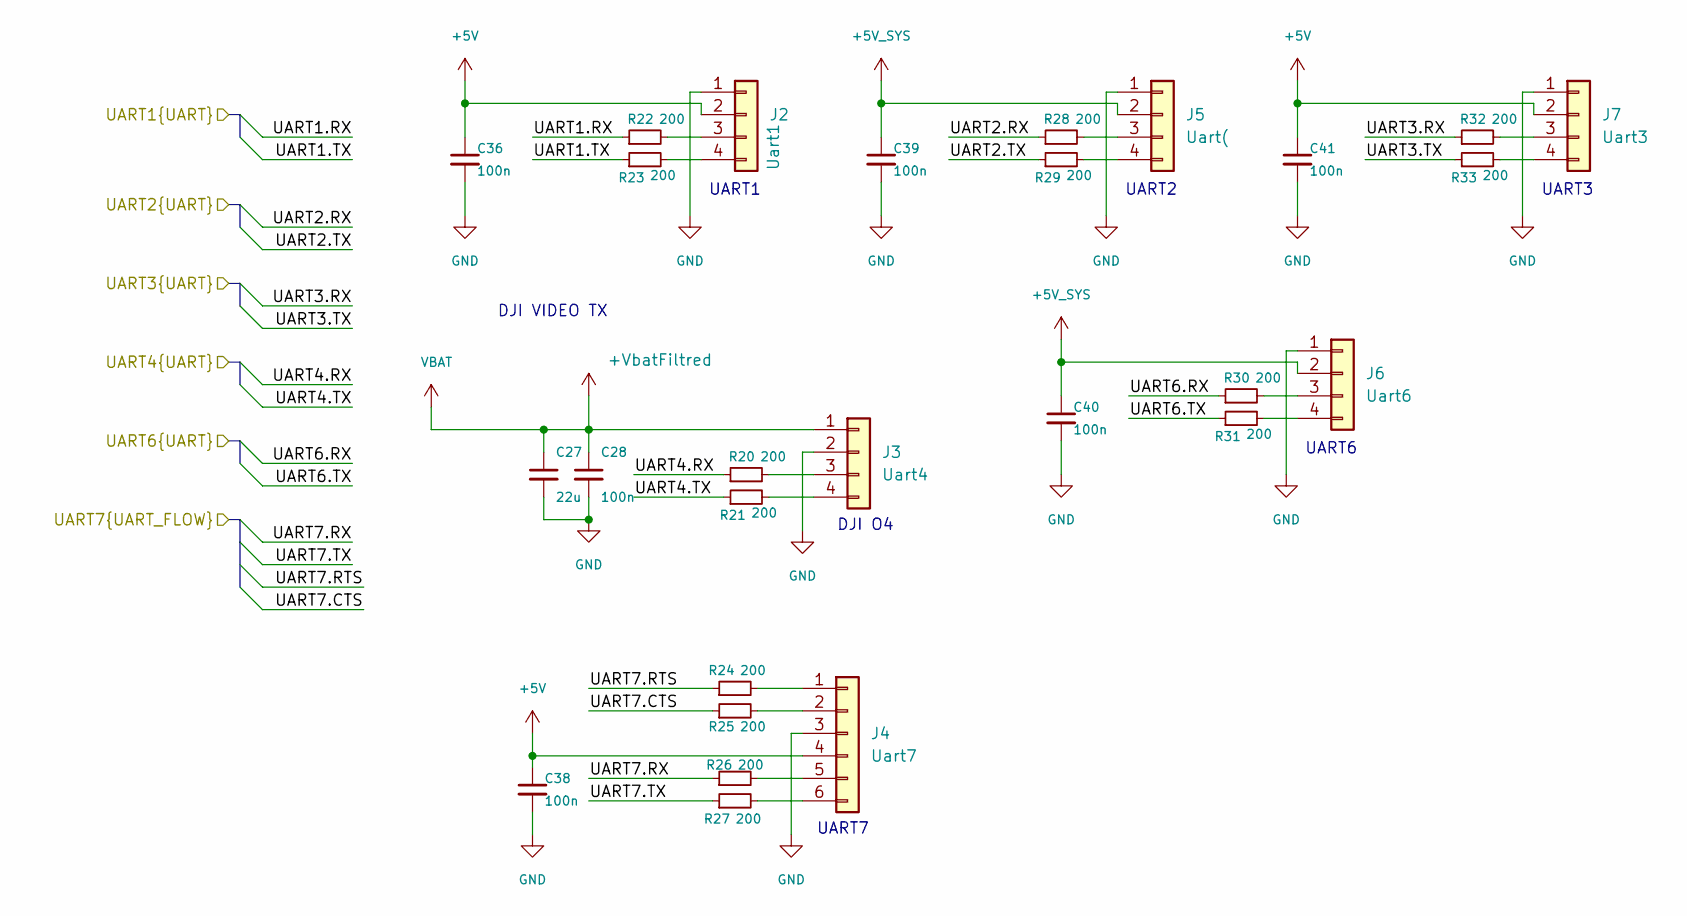
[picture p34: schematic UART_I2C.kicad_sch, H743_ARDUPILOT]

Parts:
C27: 22u; C_0805_2012Metric; MPN CL21A226MAYNNNE; DigiKey Part Number 1276-CL21A226MAYNNNECT-ND
C28: 100n; C_0402_1005Metric; MPN GCM155R71H104KE02D; DigiKey Part Number 490-10672-1-ND
C36, C38, C39, C40, C41: 100n; C_0402_1005Metric; MPN CL05B104KO5NNNC; DigiKey Part Number 1276-1001-1-ND
J2: Uart1; SolderPadArray_1x04_P2.54mm_1x1mm; DigiKey Status Element PCB; aucun composant achete
J3: Uart4; SolderPadArray_1x04_P2.54mm_1x1mm; DigiKey Status Element PCB; aucun composant achete
J4: Uart7; SolderPadArray_1x06_P2.54mm_1x1mm; DigiKey Status Element PCB; aucun composant achete
J5: Uart(; SolderPadArray_1x04_P2.54mm_1x1mm; DigiKey Status Element PCB; aucun composant achete
J6: Uart6; SolderPadArray_1x04_P2.54mm_1x1mm; DigiKey Status Element PCB; aucun composant achete
J7: Uart3; SolderPadArray_1x04_P2.54mm_1x1mm; DigiKey Status Element PCB; aucun composant achete
R20, R21, R22, R23, R24, R25, R26, R27, R28, R29, R30, R31, R32, R33: 200; R_0402_1005Metric; MPN RC0402FR-07200RL; DigiKey Specs 200 ±1%, 0402 (1005), thick film

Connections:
+5V: C36.1, C38.1, C41.1, J2.2, J4.4, J7.2; also elsewhere on the board
+5V_SYS: C39.1, C40.1, J5.2, J6.2; also elsewhere on the board
+9V: C27.1, C28.1, J3.1; also elsewhere on the board
/MCU/UART1.RX: R22.1; also elsewhere on the board
/MCU/UART1.TX: R23.1; also elsewhere on the board
/MCU/UART2.RX: R28.1; also elsewhere on the board
/MCU/UART2.TX: R29.1; also elsewhere on the board
/MCU/UART3.RX: R32.1; also elsewhere on the board
/MCU/UART3.TX: R33.1; also elsewhere on the board
/MCU/UART4.RX: R20.1; also elsewhere on the board
/MCU/UART4.TX: R21.1; also elsewhere on the board
/MCU/UART6.RX: R30.1; also elsewhere on the board
/MCU/UART6.TX: R31.1; also elsewhere on the board
/MCU/UART7.CTS: R25.1; also elsewhere on the board
/MCU/UART7.RTS: R24.1; also elsewhere on the board
/MCU/UART7.RX: R26.1; also elsewhere on the board
/MCU/UART7.TX: R27.1; also elsewhere on the board
GND: C27.2, C28.2, C36.2, C38.2, C39.2, C40.2, C41.2, J2.1, J3.2, J4.3, J5.1, J6.1, J7.1; also elsewhere on the board
unnamed: J2.3, R22.2
unnamed: J2.4, R23.2
unnamed: J3.3, R20.2
unnamed: J3.4, R21.2
unnamed: J4.1, R24.2
unnamed: J4.2, R25.2
unnamed: J4.5, R26.2
unnamed: J4.6, R27.2
unnamed: J5.3, R28.2
unnamed: J5.4, R29.2
unnamed: J6.3, R30.2
unnamed: J6.4, R31.2
unnamed: J7.3, R32.2
unnamed: J7.4, R33.2

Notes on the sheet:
DJI O4
UART3
UART1
UART6
UART2
UART7
DJI VIDEO TX

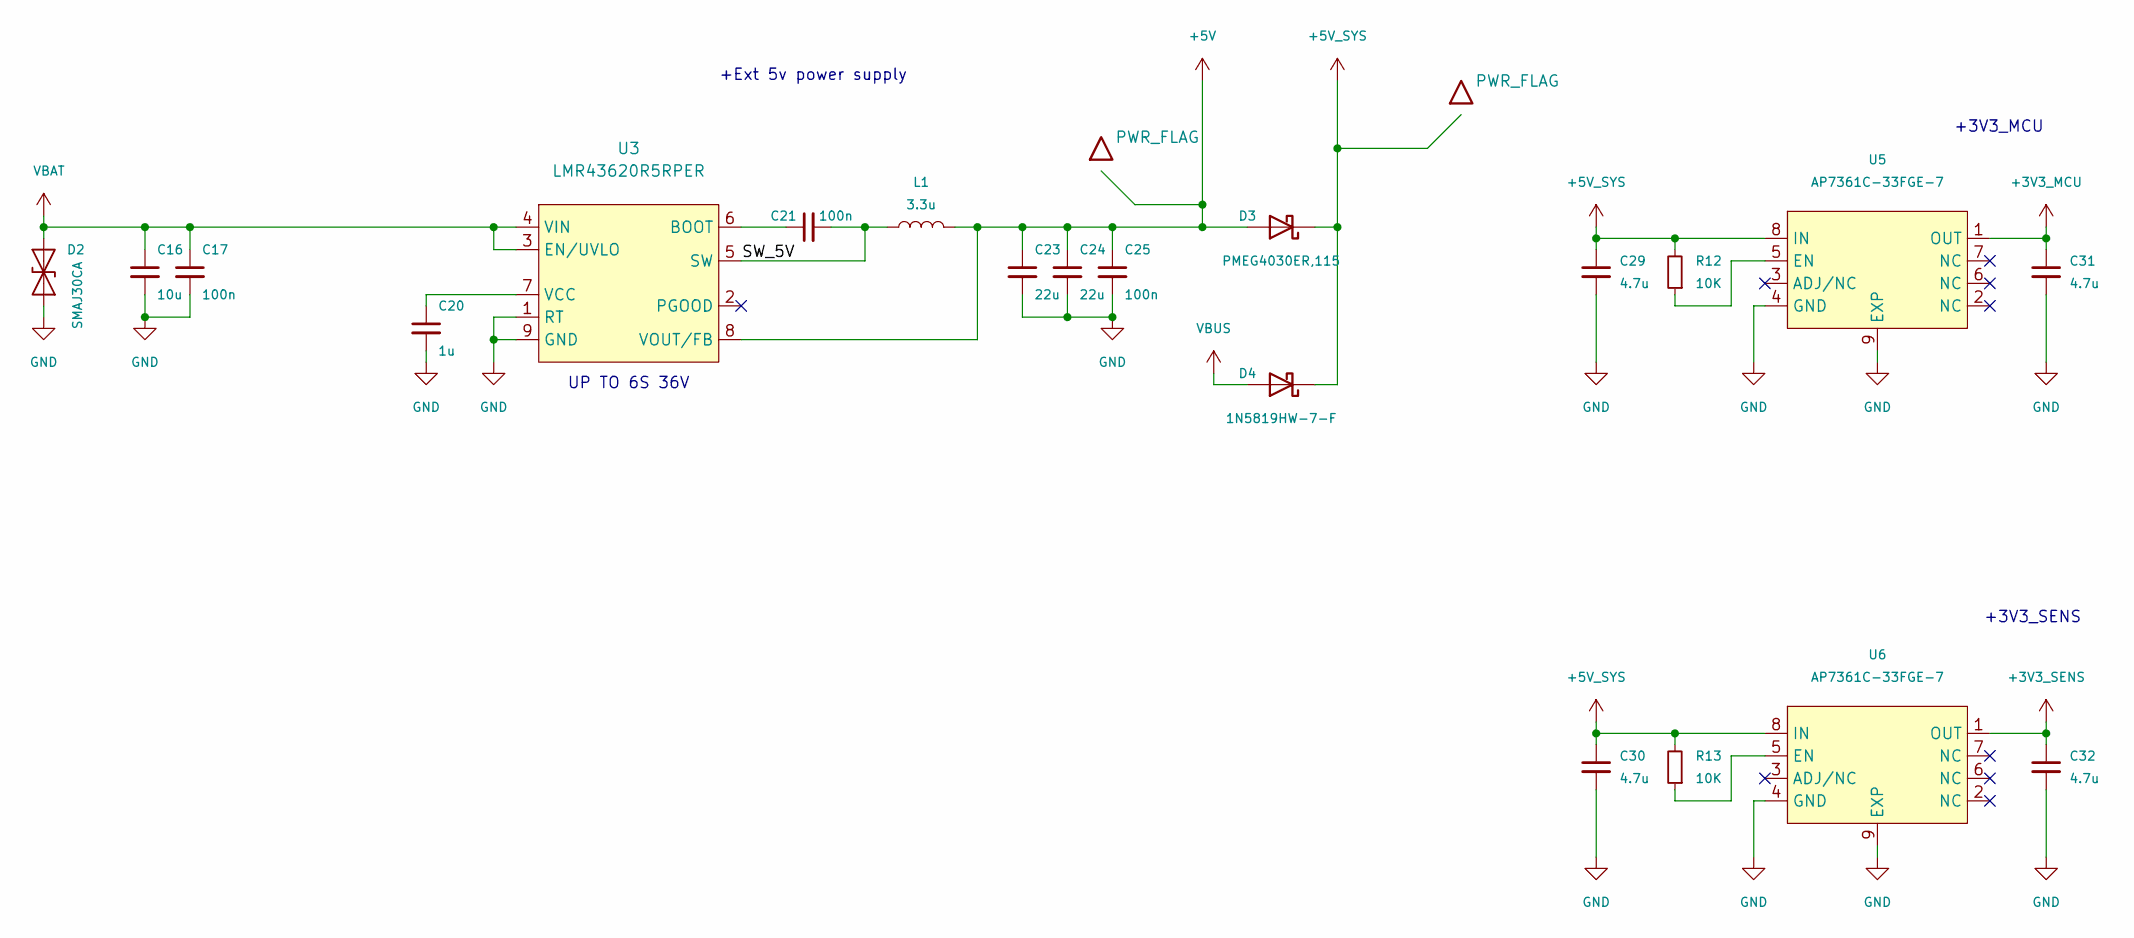
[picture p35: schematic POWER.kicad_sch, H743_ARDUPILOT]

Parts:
C16: 10u; C_0805_2012Metric; MPN GRM21BR61H106KE43L; DigiKey Part Number 490-18663-1-ND
C17, C21, C25: 100n; C_0402_1005Metric; MPN GCM155R71H104KE02D; DigiKey Part Number 490-10672-1-ND
C20: 1u; C_0603_1608Metric; MPN CL10A105KB8NNNC; DigiKey Part Number 1276-1860-1-ND
C23, C24: 22u; C_0805_2012Metric; MPN CL21A226MAYNNNE; DigiKey Part Number 1276-CL21A226MAYNNNECT-ND
C29, C30, C31, C32: 4.7u; C_0603_1608Metric; MPN CL10A475KO8NNNC; DigiKey Part Number 1276-1784-1-ND
D2: SMAJ30CA; Diodes_SMA_SMAJ30CA; MPN SMAJ30CA-13-F; LCSC Part C134980
D3: PMEG4030ER,115; Nexperia_CFP3_SOD-123W; MPN PMEG4030ER,115; DigiKey Part Number 1727-5313-1-ND
D4: 1N5819HW-7-F; D_SOD-123; MPN 1N5819HW-7-F; DigiKey Part Number 1N5819HW-FDICT-ND
L1: 3.3u; L_Coilcraft_XGL4030; MPN XGL4030-332MEC; LCSC C6012410
R12, R13: 10K; R_0402_1005Metric; MPN RC0402FR-0710KL; DigiKey Specs 10K ±1%, 0402 (1005), thick film
U3: LMR43620R5RPER; TI_RPE0009B_VQFN-HR-9_2x2mm; MPN LMR43620R5RPER; LCSC Part C32712896
U5, U6: AP7361C-33FGE-7; Diodes_U-DFN3030-8_TypeE; MPN AP7361C-33FGE-7; LCSC Part C151007

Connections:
+3V3_MCU: C31.1, U5.1 (OUT); also elsewhere on the board
+3V3_SENS: C32.1, U6.1 (OUT); also elsewhere on the board
+5V: C23.1, C24.1, C25.1, D3.2 (A), L1.2, U3.8 (VOUT/FB); also elsewhere on the board
+5V_SYS: C29.1, C30.1, D3.1 (K), D4.1 (K), R12.2, R13.2, U5.8 (IN), U6.8 (IN); also elsewhere on the board
/POWER/SW_5V: C21.2, L1.1, U3.5 (SW)
GND: C16.2, C17.2, C20.2, C23.2, C24.2, C25.2, C29.2, C30.2, C31.2, C32.2, D2.1 (A1), U3.1 (RT), U3.9 (GND), U5.4 (GND), U5.9 (EXP), U6.4 (GND), U6.9 (EXP); also elsewhere on the board
unnamed: C21.1, U3.6 (BOOT)
unnamed: C20.1, U3.7 (VCC)
unnamed: R12.1, U5.5 (EN)
unnamed: R13.1, U6.5 (EN)
VBAT: C16.1, C17.1, D2.2 (A2), U3.3 (EN/UVLO), U3.4 (VIN); also elsewhere on the board
VBUS: D4.2 (A); also elsewhere on the board

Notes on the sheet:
+3V3_SENS
+Ext 5v power supply
+3V3_MCU
UP TO 6S 36V

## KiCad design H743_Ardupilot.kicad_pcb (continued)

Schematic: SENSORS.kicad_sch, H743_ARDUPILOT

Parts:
C44, C45, C46: 4.7u; C_0402_1005Metric; MPN CL05A475MP5NRNC; DigiKey Part Number 1276-1482-1-ND
C47, C48, C49, C50, C51, C52: 100n X7R; C_0402_1005Metric; MPN CL05B104KO5NNNC; DigiKey Part Number 1276-1001-1-ND
C53, C54, C55, C56: 100n; C_0402_1005Metric; MPN CL05B104KO5NNNC; DigiKey Part Number 1276-1001-1-ND
J8: I2C1; SolderPadArray_1x04_P2.54mm_1x1mm; DigiKey Status Element PCB; aucun composant achete
J9: I2C_2; SolderPadArray_1x04_P2.54mm_1x1mm; DigiKey Status Element PCB; aucun composant achete
R34, R35, R36: 0R; R_0402_1005Metric; MPN RC0402JR-070RL; DigiKey Specs 0 Ω jumper, 0402 (1005), thick film
R37, R38: 4.7K; R_0402_1005Metric; MPN RC0402FR-074K7L; DigiKey Specs 4.7 kΩ ±1%, 0.063 W, 0402
U9: BMI088; BMI088_LGA16_4.5x3mm; MPN BMI088; DigiKey Specs 6-axis accel + gyro, I2C/SPI, LGA-16 4.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
U10: LSM6DSV16X; LSM6DSV16X_LGA14_3x2.5mm; MPN LSM6DSV16XTR; DigiKey Part Number 497-LSM6DSV16XTRCT-ND
U11: ICM-45686; TDK_ICM45686_LGA14_3x2.5mm; MPN ICM-45686; DigiKey Product ID 24374985
U12: BMP581; QFN10_BMP581_BOS; MPN BMP581; DigiKey Part Number 828-BMP581CT-ND
U13: DPS368XTSA1; Infineon_DPS368_PG-VLGA-8-2; MPN DPS368XTSA1; LCSC Part C3232508

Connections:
+3V3_MCU: C50.1, C51.1, C52.1, C53.1, C54.1, R37.1, R38.1, U9.11 (VDDIO), U10.5 (VDDIO), U11.5 (VDDIO), U12.1 (VDDIO), U13.2 (CSB), U13.6 (VDDIO); also elsewhere on the board
+3V3_SENS: C44.1, C45.1, C46.1, C47.1, C48.1, C49.1, C55.1, C56.1, U9.3 (VDD), U10.8 (VDD), U11.8 (VDD), U12.10 (VDD), U13.8 (VDD); also elsewhere on the board
+5V_SYS: J8.1, J9.1; also elsewhere on the board
/MCU/I2C1.SCL: J8.4; also elsewhere on the board
/MCU/I2C1.SDA: J8.3; also elsewhere on the board
/MCU/I2C2.SCL: J9.4, R37.2, U13.4 (SCL); also elsewhere on the board
/MCU/I2C2.SDA: J9.3, R38.2, U13.3 (SDA); also elsewhere on the board
/MCU/IMU1_CLKIN: R35.1; also elsewhere on the board
/MCU/IMU1_DRDY: R34.1; also elsewhere on the board
/MCU/IMU2_DRDY: R36.2; also elsewhere on the board
/MCU/IMU3_A_CS: U9.14 (~CSB1); also elsewhere on the board
/MCU/IMU3_G_CS: U9.5 (~CSB2); also elsewhere on the board
/MCU/SPI1.CS: U11.12 (CS); also elsewhere on the board
/MCU/SPI1.MISO: U11.1 (SDO/AD0); also elsewhere on the board
/MCU/SPI1.MOSI: U11.14 (SDI/SDIO/SDA); also elsewhere on the board
/MCU/SPI1.SCLK: U11.13 (SCLK/SCL); also elsewhere on the board
/MCU/SPI2.CS: U12.6 (CSB); also elsewhere on the board
/MCU/SPI2.MISO: U12.5 (SDO); also elsewhere on the board
/MCU/SPI2.MOSI: U12.4 (SDI); also elsewhere on the board
/MCU/SPI2.SCLK: U12.2 (SCK); also elsewhere on the board
/MCU/SPI3.MISO: U9.10 (SDO2), U9.15 (SDO1); also elsewhere on the board
/MCU/SPI3.MOSI: U9.9 (SDI/SDA); also elsewhere on the board
/MCU/SPI3.SCLK: U9.8 (SCK/SCL); also elsewhere on the board
/MCU/SPI4.CS: U10.12 (CS); also elsewhere on the board
/MCU/SPI4.MISO: U10.1 (SDO/SA0); also elsewhere on the board
/MCU/SPI4.MOSI: U10.14 (SDA); also elsewhere on the board
/MCU/SPI4.SCLK: U10.13 (SCL); also elsewhere on the board
GND: C44.2, C45.2, C46.2, C47.2, C48.2, C49.2, C50.2, C51.2, C52.2, C53.2, C54.2, C55.2, C56.2, J8.2, J9.2, U9.2 (GNDA), U9.4 (GNDA), U9.6 (GNDIO), U9.7 (PS), U10.2 (SDx/AH1/Qvar1), U10.3 (SCx/AH2/Qvar2), U10.6 (GND), U10.7 (GND), U11.6 (GND), U12.3 (VSS), U12.7 (INT), U12.8 (VSS), U12.9 (VSS), U13.1 (GND), U13.7 (GND); also elsewhere on the board
unnamed: R36.1, U10.4 (INT1)
unnamed: R34.2, U11.4 (INT1)
unnamed: R35.2, U11.9 (INT2/FSYNC/CLKIN)

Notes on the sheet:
I2C_1
I2C_2

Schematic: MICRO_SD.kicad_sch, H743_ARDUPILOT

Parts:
C57: 1u; C_0402_1005Metric; MPN CL05A105KA5NQNC; DigiKey Part Number 1276-1445-1-ND
C58: 100n; C_0402_1005Metric; MPN CL05B104KO5NNNC; DigiKey Part Number 1276-1001-1-ND
J12: 10067099-200LF; Amphenol_10067099-200LF_RevH; MPN 10067099-200LF; LCSC Part C5408015
R41, R42, R43, R44, R45, R46: 10K; R_0402_1005Metric; MPN RC0402FR-0710KL; DigiKey Specs 10K ±1%, 0402 (1005), thick film

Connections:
+3V3_MCU: C57.1, C58.1, J12.4 (VDD), R41.2, R42.2, R43.2, R44.2, R45.2, R46.2; also elsewhere on the board
/MCU/SDIO.CK: J12.5 (CLK), R41.1; also elsewhere on the board
/MCU/SDIO.CMD: J12.3 (CMD), R42.1; also elsewhere on the board
/MCU/SDIO.D0: J12.7 (DAT0), R43.1; also elsewhere on the board
/MCU/SDIO.D1: J12.8 (DAT1), R44.1; also elsewhere on the board
/MCU/SDIO.D2: J12.1 (DAT2), R45.1; also elsewhere on the board
/MCU/SDIO.D3: J12.2 (DAT3/CD), R46.1; also elsewhere on the board
GND: C57.2, C58.2, J12.6 (VSS), J12.9 (CD1), J12.10 (CD2); also elsewhere on the board

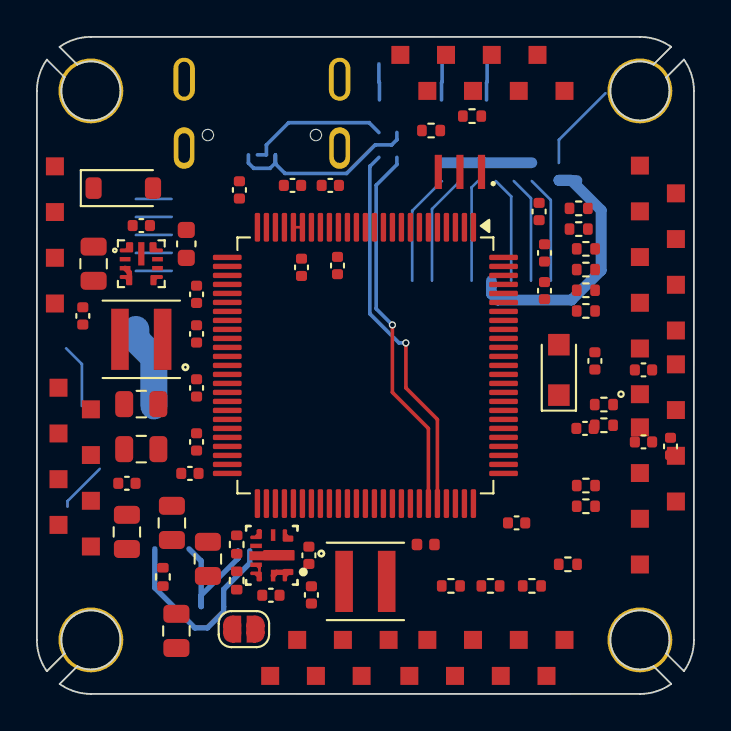
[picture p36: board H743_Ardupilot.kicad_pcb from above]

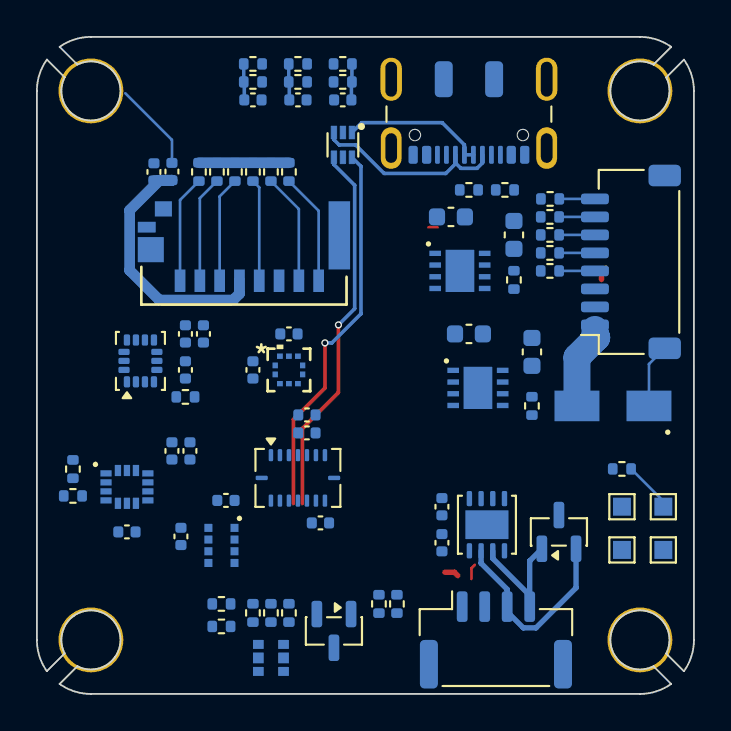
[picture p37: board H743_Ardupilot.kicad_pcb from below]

Board: 6 copper layers, 36.5 x 36.5 mm, 156 parts (77 on the bottom side), 123 nets.

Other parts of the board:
C18, C37: 10u; C_0805_2012Metric
C19, C22: 100n; C_0402_1005Metric
C26: 22u; C_0805_2012Metric
L2: 3.3u; L_Coilcraft_XGL4030
R8, R10: 100K; R_0402_1005Metric
R9: 16.5k; R_0402_1005Metric
R11: 12.4K; R_0402_1005Metric
U4: LMR604303SRAKRQ1; TI_RAK0009A_WQFN-HR-9_2.5x2.0mm

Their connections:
+9V: C26.1, C37.1, L2.2, R8.2, R10.2; also elsewhere on the board
/POWER/SW_9V: C22.2, L2.1, U4.3 (SW)
GND: C18.2, C19.2, C26.2, C37.2, R9.1, R11.2, U4.2 (PGND); also elsewhere on the board
unnamed: C22.1, U4.4 (BOOT)
unnamed: R10.1, R11.1, U4.6 (FB)
unnamed: R9.2, U4.7 (MODE/SYNC), U4.8 (RT)
unnamed: R8.1, U4.5 (PG)
VBAT: C18.1, C19.1, U4.1 (VIN), U4.9 (EN); also elsewhere on the board

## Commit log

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2026-09-24 rework and work on IMUs
    [MCU.kicad_sch, MOTORS[5-8].kicad_sch, SENSORS.kicad_sch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]
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2026-09-25 upsadte SPI4 set to Baro
    [BUZZER.kicad_sch, CAN.kicad_sch, H743_Ardupilot.kicad_sch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]
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2026-09-25 remove 9v_EN 9v power supply alwaye activated
    [H743_Ardupilot.kicad_sch, MCU.kicad_sch, POWER.kicad_sch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]
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2026-09-25 re annotate componant globaly
    [ANALOG_SENS.kicad_sch, BUZZER.kicad_sch, CAN.kicad_sch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]
2026-09-25 solved issue on SPI1
    [H743_Ardupilot.kicad_sch, MCU.kicad_sch, POWER.kicad_sch]
2026-09-25 fix VREF+ supply and complete SPI1 wiring
    [MCU.kicad_sch]
2026-09-25 fix sensor symbols for ICM-45686 and LSM6DSV16X
    [SENSORS.kicad_sch]
2026-09-25 fix BMP581 footprint to Bosch recommended land pattern
2026-09-25 align IMU symbol pin names with manufacturer datasheets
    [SENSORS.kicad_sch]
2026-09-25 audit DigiKey metadata: MCU.kicad_sch
    [MCU.kicad_sch]
2026-09-25 audit DigiKey metadata: ANALOG_SENS.kicad_sch
    [ANALOG_SENS.kicad_sch]
2026-09-25 audit DigiKey metadata: CAN.kicad_sch
    [CAN.kicad_sch]
2026-09-25 audit DigiKey metadata: POWER
    [POWER.kicad_sch]
2026-09-25 audit DigiKey metadata: SENSORS
    [SENSORS.kicad_sch]
2026-09-25 audit DigiKey metadata: BUZZER.kicad_sch
    [BUZZER.kicad_sch]
2026-09-25 audit DigiKey metadata: MOTORS[1-4].kicad_sch
    [MOTORS[1-4].kicad_sch]
2026-09-25 audit DigiKey metadata: UART_I2C.kicad_sch
    [UART_I2C.kicad_sch]
2026-09-25 audit DigiKey metadata: MICRO_SD.kicad_sch
    [MICRO_SD.kicad_sch]
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2026-09-25 fix BMP581 library metadata and footprint alias
2026-09-25 fill verified DigiKey pricing for 50V power capacitors
    [POWER.kicad_sch]
2026-09-25 add audited DigiKey BOM export
    [BOM_DigiKey.csv]
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2026-09-25 refresh ICM-45686 from DigiKey and verified CAD symbol
    [SENSORS.kicad_sch]
2026-09-25 update ICM-45686 DigiKey BOM data
    [BOM_DigiKey.csv]
2026-09-25 fix malformed ICM-45686 KiCad symbol library
2026-09-25 fix embedded ICM-45686 symbol definition
    [SENSORS.kicad_sch]
2026-09-25 update embedded ICM-45686 readable symbol
    [SENSORS.kicad_sch]
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2026-09-25 fix MatekH743 SPI4 I2C and SPI1 pin mapping
    [MCU.kicad_sch]
2026-09-25 fix MCU sensor hierarchy pin alignment
    [H743_Ardupilot.kicad_sch]
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2026-09-25 add pad for buzzer ouput
    [BUZZER.kicad_sch]
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2026-09-25 use exact XGL4020 footprint for power inductors
    [POWER.kicad_sch]
2026-09-25 update BOM for exact XGL4020 footprints
    [BOM_DigiKey.csv]
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2026-09-25 upgrade 5V OR diode D4 to PMEG4030ER 3A
    [POWER.kicad_sch]
2026-09-25 update BOM for PMEG4030ER D4
    [BOM_DigiKey.csv]
2026-09-25 fix D4 PMEG4030ER metadata
    [POWER.kicad_sch]
2026-09-25 fix D4 PMEG4030ER DigiKey BOM data
    [BOM_DigiKey.csv]
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2026-09-25 use official KiCad CFP3 footprint for D4
    [POWER.kicad_sch]
2026-09-25 align D4 BOM footprint with official KiCad CFP3
    [BOM_DigiKey.csv]
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2026-09-25 remove stale XGL4020 audit notes
    [BOM_DigiKey.csv]
2026-09-25 correct final pre-PCB audit status
2026-09-25 normalize 3V3 rail labels
    [POWER.kicad_sch]
2026-09-25 normalize MCU 3V3 test point label
    [MCU.kicad_sch]
2026-09-25 clean CAN schematic wording
    [CAN.kicad_sch]
2026-09-25 move all sensor VDDIO rails to 3V3_SENS
    [SENSORS.kicad_sch]
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2026-09-25 restore sensor VDDIO rails to 3V3_MCU
    [SENSORS.kicad_sch]
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2026-09-25 assign Matek-style solder pad footprints in BUZZER.kicad_sch
    [BUZZER.kicad_sch]
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2026-09-25 resolve J1-J9 and J12 solder pad footprints
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2026-09-25 fix H743 pin mapping and add LED strip pad
    [MCU.kicad_sch]
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2026-09-25 document corrected H743 mapping and LED pad
2026-09-25 revert unsafe H743 mapping changes in MCU.kicad_sch
    [MCU.kicad_sch]
2026-09-25 revert unsafe H743 mapping changes in H743_Ardupilot.kicad_sch
    [H743_Ardupilot.kicad_sch]
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2026-09-26 revertee RX / TX
    [MCU.kicad_sch]
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2026-09-26 revert tx / rx
    [MCU.kicad_sch]
2026-09-26 Align D1 Everlight M01 metadata with verified manufacturer/DigiKey status
    [MCU.kicad_sch]
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2026-09-26 Fix D1-only audit date update
    [MCU.kicad_sch]
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2026-09-26 Fix 10067099-200LF RevH footprint from manufacturer PCB layout
2026-09-26 Update microSD footprint audit after RevH correction
    [MICRO_SD.kicad_sch]
2026-09-26 Record corrected Amphenol RevH land pattern
    [BOM_DigiKey.csv]
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2026-09-26 Use verified LMR43620 footprint and add sourcing metadata
    [POWER.kicad_sch]
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2026-09-26 Use local RAK0009A footprint and add LMR604303 sourcing metadata
    [POWER.kicad_sch]
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2026-09-26 Use local JAE USB-C footprint and add USB1 sourcing metadata
    [H743_Ardupilot.kicad_sch]
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2026-09-27 Migrate SM04B-GHS-TB(LF)(SN) to verified JST symbol and footprint
    [CAN.kicad_sch]
2026-09-27 Migrate SM08B-SRSS-TB(LF)(SN) to verified JST symbol and footprint
    [MOTORS[1-4].kicad_sch]
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2026-09-27 Localize power IC symbols and verify AP7361C package
    [POWER.kicad_sch]
2026-09-27 Correct USB1 footprint from DX07S016JA1R1500 supplier CAD
2026-09-27 Correct USB1 symbol pin map and sourcing metadata
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2026-09-27 Fix CAN schematic symbol and update SMAJ30CA footprint
    [CAN.kicad_sch, H743_Ardupilot.kicad_pcb, POWER.kicad_sch]
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2026-09-27 Sync U1 PCB footprint name with source CAD
    [H743_Ardupilot.kicad_pcb]
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2026-09-27 Sync U1 and D2 dedicated footprint library names on PCB
    [H743_Ardupilot.kicad_pcb]
2026-09-27 Review component footprints, restore local libraries and reconcile PCB pads
    [ANALOG_SENS.kicad_sch, BOM_DigiKey.csv, BUZZER.kicad_sch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]
2026-09-27 Optimize PCB component placement by functional blocks and EMC constraints
    [H743_Ardupilot.kicad_pcb]
2026-09-27 Move UART resistors to top and resolve PCB placement overlaps
    [H743_Ardupilot.kicad_pcb]
2026-09-27 Refine PCB placement for sensor, microSD and routing constraints
    [H743_Ardupilot.kicad_pcb]
2026-09-27 Optimize PCB placement: move power to front, clear USB1 and recess microSD
    [H743_Ardupilot.kicad_pcb]
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2026-09-27 Apply EMC layout review: move VCAPs to top and refresh PCB status
    [H743_Ardupilot.kicad_pcb]
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2026-09-27 Replace EOL CAN transceiver with TJA1057GTK/3Z
    [CAN.kicad_sch]
2026-09-27 Create oscillator isolation and Bosch MEMS keepouts
    [H743_Ardupilot.kicad_pcb]
2026-09-27 Add 22R optional SDIO clock series damping resistor
    [MICRO_SD.kicad_sch]
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2026-09-27 Add inner GND planes and perimeter stitching vias
    [H743_Ardupilot.kicad_pcb]
2026-09-27 Record oscillator MEMS SDIO and ground-plane EMC changes
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2026-09-27 Resolve SDIO series resistor reference collision
    [MICRO_SD.kicad_sch]
2026-09-27 Fix SDIO resistor reference and improve 9V inductor isolation
    [H743_Ardupilot.kicad_pcb]
2026-09-27 Tighten MCU and IMU decoupling placement
    [H743_Ardupilot.kicad_pcb]
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2026-09-28 Audit FC_01 libraries nets supplier specs and placement
    [BOM_DigiKey.csv, BOM_FR.csv, CAN.kicad_sch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]
2026-09-28 Move MCU resonator to front and correct placement clearances
    [H743_Ardupilot.kicad_pcb]
2026-09-28 Resolve USB through-hole conflicts and remove premature vias
    [H743_Ardupilot.kicad_pcb]
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2026-09-28 Remove placement short and repair BMP581 courtyard
    [H743_Ardupilot.kicad_pcb]
2026-09-28 Replace USB1 envelope with detailed DX07S016JA1R1500 STEP
    [JAE_DX07S016JA1R1500_envelope.step]
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2026-09-28 Define SPI2 bus members across MCU and sensors
    [H743_Ardupilot.kicad_sch, MCU.kicad_sch, SENSORS.kicad_sch]
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2026-09-28 Declare external and regulator power sources for ERC
    [CAN.kicad_sch, H743_Ardupilot.kicad_sch, MCU.kicad_sch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]
2026-09-28 Correct ERC pin models and power connectivity
    [CAN.kicad_sch, H743_Ardupilot.kicad_pcb, H743_Ardupilot.kicad_sch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]
2026-09-28 Resolve three KiCad library symbol mismatches
    [MCU.kicad_sch, POWER.kicad_sch]
2026-09-28 Orient USB1 3D model to match bottom-side receptacle
    [H743_Ardupilot.kicad_pcb]
2026-09-28 Use supplied USB1 STEP model with verified placement
    [DX07S016JA1R1500.step, H743_Ardupilot.kicad_pcb]
2026-09-28 Fix Edge.Cuts self-intersection at top-right contour junction
    [H743_Ardupilot.kicad_pcb]
2026-09-28 Fix mounting-hole copper-to-edge clearances using LEVIA pad diameter
    [H743_Ardupilot.kicad_pcb]
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2026-09-28 Fix left Edge.Cuts self-intersection
    [H743_Ardupilot.kicad_pcb]
2026-09-28 Fix exact Edge.Cuts endpoint continuity
    [H743_Ardupilot.kicad_pcb]
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2026-09-28 Fix KiCad DRC exclusion format for validated footprint overrides
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2026-09-29 Revert unsafe critical-placement moves after courtyard audit
    [H743_Ardupilot.kicad_pcb]
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2026-09-29 Correct BMP581 footprint to Bosch recommended land pattern
2026-09-29 Fix U12 BMP581 footprint to Bosch DS004-13 land pattern
    [COMPONENTS.csv, H743_Ardupilot.kicad_pcb, SENSORS.kicad_sch]
2026-09-29 PCB: correct sensor keepouts and BMP581 INT type
    [H743_Ardupilot.kicad_pcb, SENSORS.kicad_sch]
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2026-09-29 ci: fix KiCad nightly CLI name
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2026-09-29 pcb: clean silkscreen refs and fix U9 mask
    [H743_Ardupilot.kicad_pcb]
2026-09-29 pcb: make U9 BMI088 keepout visible and centered
    [H743_Ardupilot.kicad_pcb]
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2026-09-29 PCB: define 6-layer FC_01 stackup and layer roles
    [H743_Ardupilot.kicad_pcb]
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2026-09-29 PCB: start routing local power and regulator nets
    [H743_Ardupilot.kicad_pcb]
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2026-09-30 PCB: remove unsafe first-pass routes after KiCad 10 DRC
    [H743_Ardupilot.kicad_pcb]
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2026-10-01 CI: run autoroute from corrected PCB
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2026-10-04 Update C27 to 22uF 35V X7R in 1210
    Use Samsung CL32B226KLV6PJE (22uF, +/-10%, 35V, X7R) for C27 in UART_I2C. Add a visible Tension nominale field and dielectric/tolerance properties. Link the exact manufacturer specsheet and clear purchasing data belonging to the old CL21A226 part. Add project-local generic KiCad 1210 footprint and STEP assets.
    Manufacturer source: https://product.samsungsem.com/mlcc/CL32B226KLV6PJ.do
    Footprint source: https://gitlab.com/kicad/libraries/kicad-footprints/-/raw/master/Capacitor_SMD.pretty/C_1210_3225Metric.kicad_mod
    STEP source: https://raw.githubusercontent.com/KiCad/kicad-packages3D/master/Capacitor_SMD.3dshapes/C_1210_3225Metric.step
    Validation: lossless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
    [C_1210_3225Metric.step, UART_I2C.kicad_sch]
2026-10-04 Add verified LMR604305SRAKRQ1 KiCad symbol, connected footprint and supplied STEP
    [LMR604305SRAKRQ1_RAK0009A.step]

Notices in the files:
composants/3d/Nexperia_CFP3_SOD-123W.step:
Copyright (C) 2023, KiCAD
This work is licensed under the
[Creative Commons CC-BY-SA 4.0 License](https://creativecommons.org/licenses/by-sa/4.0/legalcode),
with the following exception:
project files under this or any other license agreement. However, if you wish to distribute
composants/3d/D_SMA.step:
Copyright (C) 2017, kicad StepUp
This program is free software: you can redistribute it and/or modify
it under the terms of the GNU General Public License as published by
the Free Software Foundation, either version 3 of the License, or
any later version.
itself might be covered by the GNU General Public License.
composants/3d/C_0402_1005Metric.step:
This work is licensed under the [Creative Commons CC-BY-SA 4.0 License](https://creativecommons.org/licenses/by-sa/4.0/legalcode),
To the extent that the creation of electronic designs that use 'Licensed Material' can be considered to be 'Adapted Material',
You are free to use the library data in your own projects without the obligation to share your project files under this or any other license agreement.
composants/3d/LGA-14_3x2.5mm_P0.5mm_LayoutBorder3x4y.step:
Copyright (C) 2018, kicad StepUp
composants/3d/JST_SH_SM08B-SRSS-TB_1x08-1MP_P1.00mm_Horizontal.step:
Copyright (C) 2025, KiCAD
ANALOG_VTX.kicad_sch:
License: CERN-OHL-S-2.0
